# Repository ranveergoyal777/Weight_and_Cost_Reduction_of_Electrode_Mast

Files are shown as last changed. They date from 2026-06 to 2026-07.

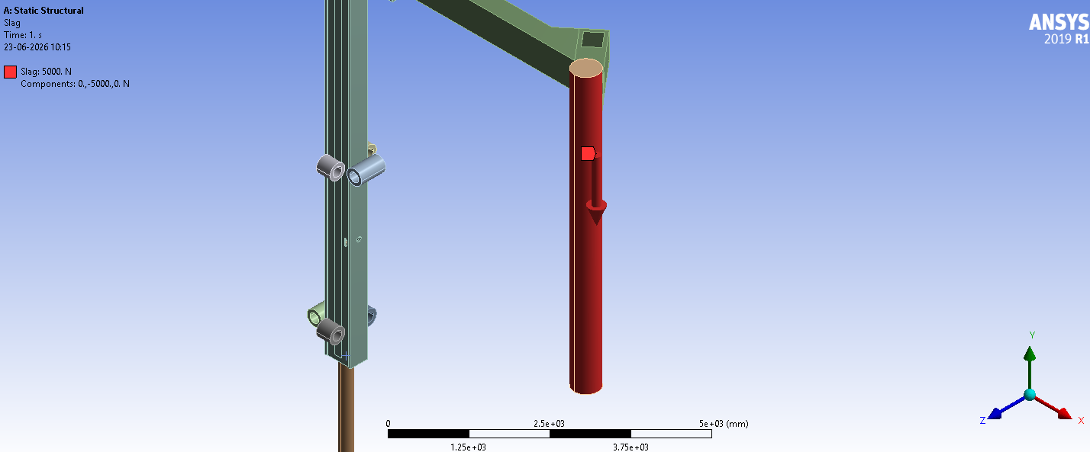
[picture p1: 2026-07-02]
508_Electrode/Side Mast 2/Photos 508 Side Mast 2/Screenshot 2026-06-23 101618.png

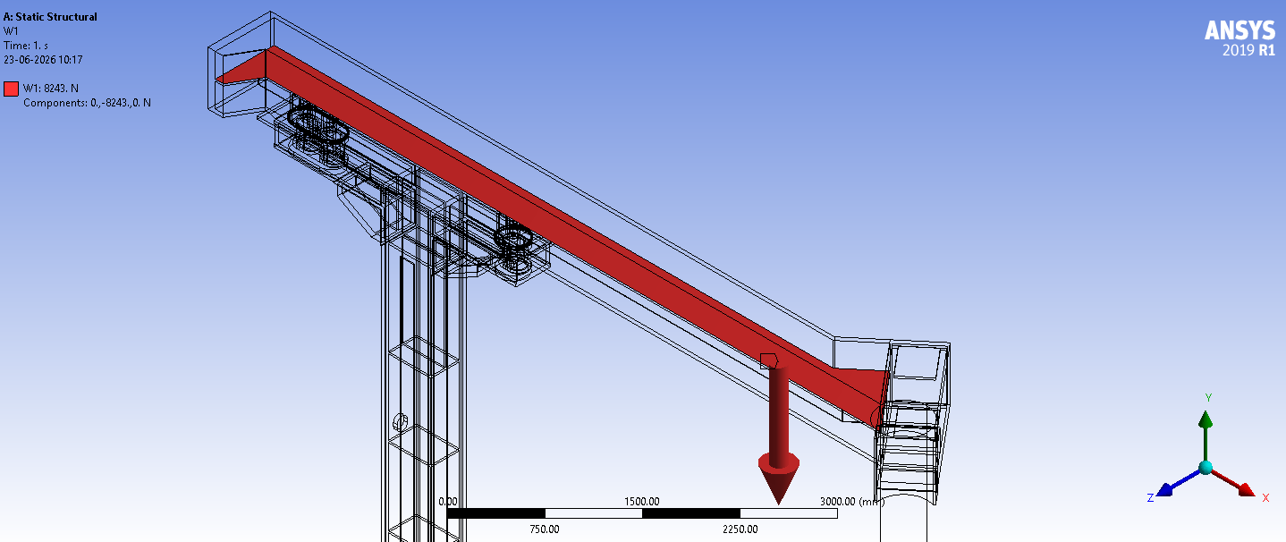
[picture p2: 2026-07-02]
508_Electrode/Side Mast 2/Photos 508 Side Mast 2/Screenshot 2026-06-23 103617.png

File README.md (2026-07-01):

# Weight & Cost Reduction of Electrode Mast – Ladle Heating Furnace (LHF)

Static structural FEA-based redesign of the electrode mast-arm assembly of a Ladle Heating Furnace, performed during a summer internship at **SMS India Pvt. Ltd.** (Metallurgy Department).

**Author:** Ranveer Goyal, B.Tech. Mechanical Engineering, IIT Ropar
**Duration:** 25 May 2026 – 3 July 2026 (6 weeks)
**Software:** SolidWorks · ANSYS Mechanical 2019 (Student)

## Overview

A Ladle Heating Furnace (LHF) uses graphite electrodes mounted on cantilevered mast-arm assemblies to arc-heat liquid steel during secondary refining. This project performs static structural FEA on the existing electrode mast-arm assemblies and proposes redesigned mast cross-sections that reduce weight and material cost while keeping stresses and deformations within allowable limits.

The work covers four configurations — side arm (E-ARM#1) and middle arm (E-ARM#2), for both 508 mm and 457 mm electrode variants — plus a comparative study of a cylindrical mast alternative.

## Methodology

1. **Manual calculations** – Free-body moment equilibrium to estimate support roller reactions and hydraulic cylinder base load, used to cross-check FEA results.
2. **CAD simplification (SolidWorks)** – Original assemblies simplified by removing non-structural hardware (pipes, brackets, fittings) while preserving internal water-cooling chambers. Removed mass compensated using an effective-density approach with a 1.3 factor of safety.
3. **FEA (ANSYS Mechanical 2019)** – Static structural analysis with frictional contact at the moment-resisting roller pair, bonded contacts elsewhere (validated against a full bolt-pretension study), and loads including self-weight, cooling water weight, dynamic water pressure (9 bar), dust load, cable weight, clamping unit weight, and slag force.
4. **Redesign & comparison** – Mast cross-sections reduced and re-analyzed; results compared against the original (Mast 1) design for stress, deformation, and base load.

## Key Results

| Configuration | Mast 1 → Mast 2 (cross-section) | Weight Reduction | Estimated Cost Saving |
|---|---|---|---|
| E-ARM#1, 508 mm | 600×410 → 550×350 mm | 14.9% (≈790 kg) | ≈ ₹3.16 lakhs |
| E-ARM#2, 508 mm | 600×410 → 550×350 mm | 15.4% (≈959 kg) | ≈ ₹3.84 lakhs |
| E-ARM#1, 457 mm | 550×400 → 500×310 mm (proposed) | 22.6% (≈1054 kg) | ≈ ₹4.21 lakhs |
| E-ARM#2, 457 mm | 550×400 → 500×310 mm | 20.4% (≈1270 kg) | ≈ ₹5.08 lakhs |

Across all configurations, peak stress and hydraulic cylinder base load were reduced or held essentially constant, while mast weight dropped by roughly 15–23%. The trade-off is increased total deformation, which remains within allowable limits in every case. A cylindrical mast alternative was also evaluated and found structurally inferior (higher stress and deformation) to the rectangular section, and was not pursued further.

## Repository Structure

```
.
├── 508_Electrode/
│   ├── Middle_Mast_1/
│   │   ├── *.stp                  # SolidWorks STEP model
│   │   ├── *.wbpj / ANSYS files   # ANSYS Workbench project and subsequent files
│   │   └── Result_Photos/         # ANSYS result plots (stress, deformation, etc.)
│   ├── Middle_Mast_2/
│   │   ├── *.stp
│   │   ├── ANSYS files
│   │   └── Result_Photos/
│   ├── Side_Mast_1/
│   │   ├── *.stp
│   │   ├── ANSYS files
│   │   └── Result_Photos/
│   └── Side_Mast_2/
│       ├── *.stp
│       ├── ANSYS files
│       └── Result_Photos/
│
├── 457_Electrode/
│   ├── Middle_Mast_1/
│   │   ├── *.stp
│   │   ├── ANSYS files
│   │   └── Result_Photos/
│   ├── Middle_Mast_2/
│   │   ├── *.stp
│   │   ├── ANSYS files
│   │   └── Result_Photos/
│   └── Side_Mast_1/
│       ├── *.stp
│       ├── ANSYS files
│       └── Result_Photos/
│   (no Side_Mast_2 — see note below)
│
├── Cylindrical_Mast/
│   ├── *.stp
│   ├── ANSYS files
│   └── Result_Photos/
│
└── Internship_Report.docx
```

**Note:** The 457 mm electrode configuration has no `Side_Mast_2` folder — the redesigned side-arm mast for this variant was not separately modelled/analyzed in ANSYS; it is a proposed design based on the validated results of the 457 mm middle arm redesign (see Section 9.3.2 of the report).

Each `Mast 1` folder contains the original cross-section model and results; each `Mast 2` folder contains the redesigned (weight/cost-reduced) cross-section model and results. The `Cylindrical_Mast` folder contains the standalone comparative study of a circular hollow section mast (Section 9.5 of the report), evaluated under the 508 mm middle-arm Mast 1 loading conditions.

## Acknowledgements

This project was carried out under the guidance of the Metallurgy Department at SMS India Pvt. Ltd., a subsidiary of SMS group GmbH.

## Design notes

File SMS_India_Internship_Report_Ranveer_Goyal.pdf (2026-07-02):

Internship Report – SMS India Pvt. Ltd. | Weight & Cost Reduction of Electrode Mast | Ranveer Goyal, IIT Ropar
SMS India Pvt. Ltd. | Summer Internship 2026 Page 1

# SUMMER INTERNSHIP REPORT

## Weight and Cost Reduction of Electrode Mast of the Ladle Heating Furnace

Submitted by

### Ranveer Goyal

2024MEB1375
B.Tech., Mechanical Engineering Indian Institute of Technology Ropar

Organization
SMS India Pvt. Ltd.
Metallurgy Department

Duration: 25 May 2026 – 3 July 2026 (6 Weeks)

## Table of Contents

## 1. Internship Overview

Organization | SMS India Pvt. Ltd.
Department | Metallurgy Department
Duration | 25 May 2026 – 3 July 2026 (6 Weeks)
Project Title | Weight and Cost Reduction of Electrode Mast of the Ladle Heating Furnace
Student | Ranveer Goyal – IIT Ropar (B.Tech. Mechanical Engineering)
Software Used | SolidWorks, ANSYS Mechanical 2019 Student

## 2. Introduction

2.1 About SMS India Pvt. Ltd.

SMS India Pvt. Ltd. is the Indian subsidiary of SMS group GmbH, a world-leading supplier of plant and machinery for the steel and non-ferrous metals industry. The Metallurgy Department focuses on primary and secondary steelmaking equipment including ladle furnaces and vacuum degassers. SMS group has supplied over 150 single-station and 40 twin-station ladle furnaces globally, with Indian installations at Bokaro, JSPL Angul, Tata Steel, JSW, SAIL, and AM/NS among others.

### 2.2 Project Objective

The objective of this project was to perform static structural FEA of the existing electrode mast and arm assemblies of a Ladle Heating Furnace (LHF), and to redesign selected mast cross-sections to achieve weight and material cost reduction while maintaining structural integrity under all operating loads.

- Study the LHF equipment and the steelmaking process.
- Perform manual force and moment calculations for the electrode mast-arm assembly.
- Rebuild simplified 3D models in SolidWorks suitable for FEA.
- Conduct static structural analysis in ANSYS Mechanical 2019 Student for both Ø508 mm and Ø457 mm electrode variants (side arm E-ARM#1 and middle arm E-ARM#2).
- Propose and validate redesigned mast cross-sections with reduced weight and cost.

## 3. Steelmaking Process Overview

As background for the LHF equipment studied in this project, a brief overview of the steelmaking route is given below.

Iron ore is processed through a sinter plant and reduced in a Blast Furnace (or via DRI) to produce liquid hot metal. This is converted to steel in a primary furnace — a Basic Oxygen Furnace (BOF), Electric Arc Furnace (EAF), or Conpro Furnace — depending on the plant configuration. The liquid steel is then tapped into a ladle and moved to the Ladle Heating Furnace (LHF) for secondary refining, where arc heating from graphite electrodes maintains the precise temperature required for casting, while alloying, desulphurization, and inert-gas stirring adjust the final chemistry. For high-grade steels, the ladle may additionally pass through a degassing unit (RH or VD/VOD) to remove dissolved gases. Finally, the refined steel is sent to the Continuous Casting Machine (CCM) and solidified into billets, blooms, slabs, or rounds for downstream rolling.

The LHF — the focus of this project — therefore functions as a critical buffer and refining station between primary steelmaking and casting, and its electrode mast-arm assembly must reliably withstand continuous mechanical and thermal loads during operation.

## 4. Ladle Heating Furnace – Equipment Description

### 4.1 LHF Types

Single-station LHFs have one treatment position and are compact and energy-efficient (30–350 t). Twin-station LHFs have two treatment positions sharing a common power supply, offering greater operational flexibility and are preferred for superior-quality steel grades (120–350 t).

### 4.2 Key Components

- Water-Cooled Roof: Dome-shaped or skirt-type, made of water-cooled pipes. Fitted with pneumatically-operated flap gates for sampling and temperature measurement, an alloy chute, wire feeding funnel, and fume elbow connecting to the fume extraction system.
- Electrode Regulation System: The SMS X-Pact® SynReg system regulates electrode position via a primary impedance/current control loop and a secondary dynamic adjustment loop, minimizing electrode consumption and energy use.
- Electrode Arms and Mast: The structural assembly that holds and positions the graphite electrodes (detailed in Section 5).
- High Current System: Flexible water-cooled cables carry the arc current from the transformer to the electrode arms.
- Argon Top Lance / Bottom Purging: For emergency stirring and inert gas homogenization through porous plugs.
- Wire Feeding Station: Feeds alloy or treatment wires into the ladle.
- Automatic Temperature & Sampling Lance: For automated steel temperature measurement and sampling.
- Fume Extraction System: Captures and cleans furnace off-gases.

## 5. Electrode Mast-Arm System Description

### 5.1 System Overview

The electrode mast-arm assembly is the structural backbone of the LHF. It supports and positions the three graphite electrodes (one per phase of the three-phase arc system) over the ladle. The system consists of one mast per electrode phase with a cantilevered arm. The mast translates vertically via a hydraulic cylinder to raise and lower the electrode.

### 5.2 Major Components

- Electrode Mast: The primary vertical structural member. It is a water-cooled hollow rectangular box section, with mast height varying from 6.8 m to 9.5 m depending on the configuration. Including the hydraulic cylinder stroke, the total assembly height can reach up to ~15 m. Internal water chambers (left, middle, and right) cool the mast during operation.
- Electrode Arm (E-ARM#1 – Side Arm, E-ARM#2 – Middle Arm): Cantilevered arms extending horizontally from the mast, carrying the graphite electrode at their tip. The arms contain upper and lower water-cooling chambers. The middle arm (E-ARM#2) is centrally located; the side arms (E-ARM#1) are positioned on either side.
- Graphite Electrode: Conducts the arc current to the steel bath. Standard diameters analyzed are 508 mm and 457 mm. Subject to arc force (slag force) at the tip.
- Insulating Plate: Electrically isolates the electrode arm from the mast to prevent current leakage to the structure. Connected via bolted joints.
- Support Rollers – Moment-Resisting Pair: The mast is guided along a vertical rail by a total of 8 rollers (front and back, left and right, upper and lower). One pair of diametrically-opposed rollers bears against the guide rail and reacts the overturning bending moment generated by the cantilevered arm weight. The vertical spacing between this roller pair is 3100 mm for the Ø508 mm electrode configuration (both arms) and 2900 mm for the Ø457 mm electrode configuration (both arms). The upper roller pushes in one direction; the lower roller reacts in the opposite direction, forming a moment couple.
- Support Rollers – Thermal Gap Pair: The rollers on the opposite side of the moment-resisting pair maintain a small clearance gap between them and the mast rail. This gap accommodates thermal expansion of the mast during furnace operation and prevents them from generating unwanted constraint loads under normal conditions.
- Hydraulic Cylinder: Raises and lowers the entire mast-arm assembly for electrode positioning. The cylinder rod (bottom) is fixed to the gantry structure.
- Clamping Unit: Clamps the graphite electrode securely at the arm tip. Its weight (732 kg) acts at the top surface of the arm tip.
- Water Cooling Cables (W.C. Cables): Flexible water-cooled cables carrying high current. Their weight, taken as 1565 kg, acts at the rear side of the arm.
- Cooling Water Hoses: Supply and return hoses for mast cooling water.

### 5.3 Electrode Variants Analyzed

Electrode Dia. | Arm Type | Mast 1 (Original) X-section | Mast 2 (Redesigned) X-section
508 mm | E-ARM#2 (Middle Arm) | 600 × 410 mm | 550 × 350 mm + stiffener plate
508 mm | E-ARM#1 (Side Arm) | 600 × 410 mm | 550 × 350 mm + stiffener plate
457 mm | E-ARM#1 (Side Arm) | 550 × 400 mm | Not redesigned (Mast 1 only)
457 mm | E-ARM#2 (Middle Arm) | 550 × 400 mm | 500 × 310 mm

For the Ø457 mm electrode configuration, the redesigned Mast 2 (500 × 310 mm) also incorporated plate thickness changes: the original 40 mm major-axis plate was increased to 42 mm, while the 25 mm minor-axis plate was reduced to 20 mm. For the Ø508 mm electrode configuration, the major-axis plate thickness (42 mm) was kept unchanged, while the minor-axis plate thickness was reduced from 25 mm to 20 mm.

### 5.4 Materials Used

Mast and Arm Structure (Structural Steel S355):

Property | Value | Unit
Material Grade | S355 | –
Yield Strength fy | 355 | MPa
Ultimate Strength fu | 510 | MPa
Elastic Modulus E | 210,000 | MPa
Shear Modulus G | 81,000 | MPa
Density ρ | 7,850 | kg/m³
Poisson's Ratio ν | 0.3 | –
Thermal Expansion α | 1.2 × 10⁻⁵ | /°C
Temperature Rise (operating) | 110 | °C
Thermal Stress σthermal | 6.3 | MPa

Insulating Plate (EP GC 203 – epoxy glass-cloth laminate):

Property | Value | Unit
Material Grade | EP GC 203 | –
Density ρ | 2,470 | kg/m³
Young's Modulus E | 22 | GPa
Poisson's Ratio ν | 0.2 | –

Electrode (Graphite):

Property | Value | Unit
Material | Graphite | –
Density ρ | 1,800 | kg/m³
Young's Modulus E | 10 | GPa
Poisson's Ratio ν | 0.2 | –

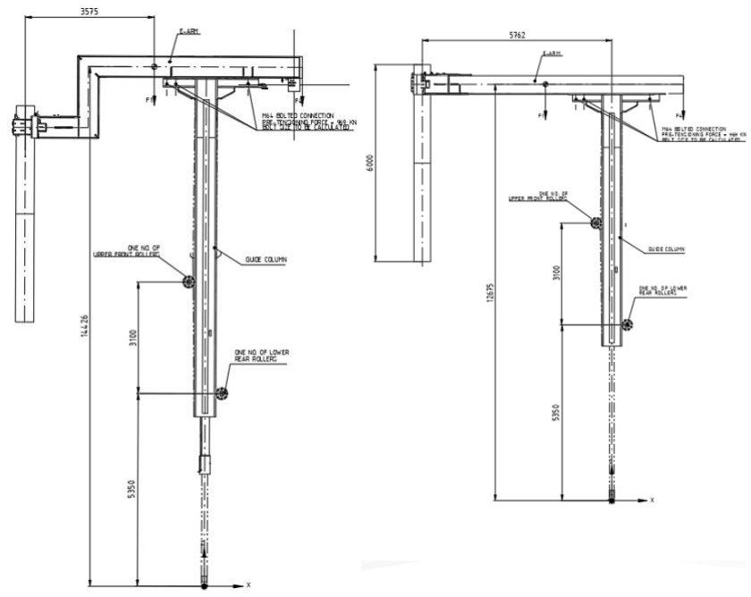
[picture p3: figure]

1. Middle and side sketches

## 6. Manual Force and Moment Calculations

Before proceeding with FEA, manual calculations were performed to estimate the reaction forces at the support rollers and the load on the hydraulic cylinder base. These results were used to verify the FEA model.

### 6.1 Methodology

The entire electrode mast-arm assembly was treated as a free body. The total bending moment about the support roller pair was found using the centre of gravity (CG) and weight of each component. Roller reactions were then calculated using moment equilibrium:

Ra = M / A | and | Rb = −Ra

where A = roller vertical spacing (3100 mm for the Ø508 mm electrode, both arms; 2900 mm for the Ø457 mm electrode, both arms)

The total vertical (axial) load on the hydraulic cylinder base equals the sum of all component weights, including the FOS-adjusted effective densities described in Section 7.3.

Cross-product mechanics were used to resolve the moments generated by each load (self-weight, water, dust, cables, clamping unit, slag) about the roller axis, producing the bending moment and roller reaction forces used to cross-check the corresponding ANSYS results in Section 9.

## 7. 3D Model Preparation in SolidWorks

### 7.1 Original Models

The original CAD assemblies of the electrode mast-arm system were provided in SolidWorks/STEP format. Each assembly included the mast, arm, electrode, insulating plate, support rollers, hydraulic cylinder, and numerous auxiliary components: pipes, hose connectors, clamps, cable brackets, and instrumentation fittings.

### 7.2 Model Simplification Strategy

Small auxiliary components significantly increase mesh element count and computation time without meaningfully affecting the global stress or deformation results. The following simplification approach was adopted:

- Removed: Pipes, hose fittings, small clamps, cable brackets, and miscellaneous hardware.
- Retained: Mast body (with internal water chambers), electrode arm, graphite electrode, insulating plate, support rollers, and hydraulic cylinder.
- Hollow internal volumes of water chambers in the mast (left/middle/right) and arm (upper/lower) were preserved intact for accurate water volume and pressure loading.
- Bodies were merged where necessary and internal geometry verified using SolidWorks Section View and Mass Properties.

### 7.3 Effective Density Compensation

To account for the mass of removed components without re-adding geometric complexity, the effective density of the mast and arm bodies was adjusted:

ρ_eff | = | (Real Total Mass of Assembly) / (Simplified Model Volume)
An additional Factor of Safety (FOS) of 1.3 was then applied by multiplying the effective density by 1.3, to conservatively account for thermal stresses and operational dynamic loads (vibration, impact from sudden stopping):
ρ_applied | = | 1.3 × ρ_eff

This same FOS of 1.3 was also applied to the water weight loads and other external forces (cables, clamping unit) to produce conservative loading. The dust load and slag force were applied without this FOS multiplier.

### 7.4 STEP File Export

Simplified assemblies were exported as STEP (.stp) files for import into ANSYS Mechanical 2019. STEP format ensures geometry fidelity and is fully compatible with ANSYS DesignModeler.

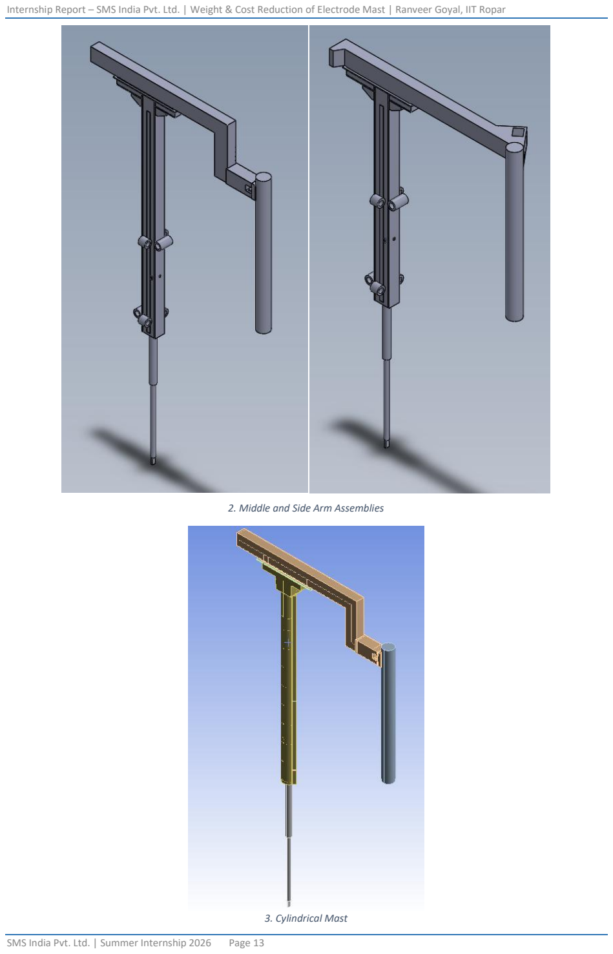
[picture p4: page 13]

2. Middle and Side Arm Assemblies
3. Cylindrical Mast

## 8. Finite Element Analysis – ANSYS Mechanical 2019

### 8.1 Material Properties

Material properties were entered in ANSYS Engineering Data for each part: structural steel (S355) for the mast, arm, and hydraulic cylinder with adjusted effective density (see Section 7.3); EP GC 203 epoxy glass-cloth laminate for the insulating plate; and graphite for the electrode (properties listed in Section 5.4).

### 8.2 Contact Definitions

The following contact pairs were defined, based on the actual contact setup used for the side and middle arm models:

Contact Pair | Type | Remarks
Support Rollers – Mast (guide column) | Frictional (μ = 0.03) | Upper-front and lower-rear roller only; 6 mm strip for surface contact.
Mast (Guide Column) – Electrode Arm | Bonded | Full attachment
Mast – Insulation – Electrode Arm | Bonded | Three-body bonded joint
Mast – Hydraulic Cylinder | Bonded | Full attachment
Electrode – Electrode Arm | Bonded | Full attachment

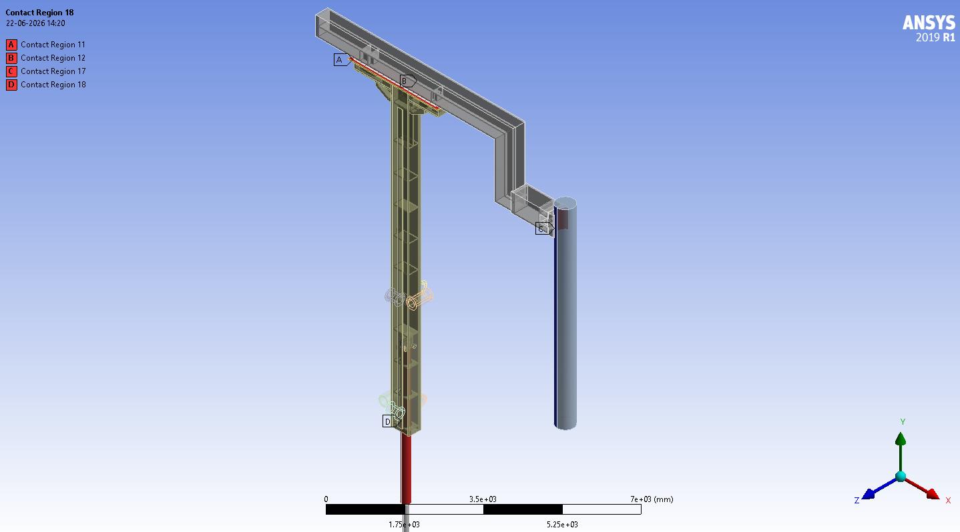
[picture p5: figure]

4. Bonded Contacts

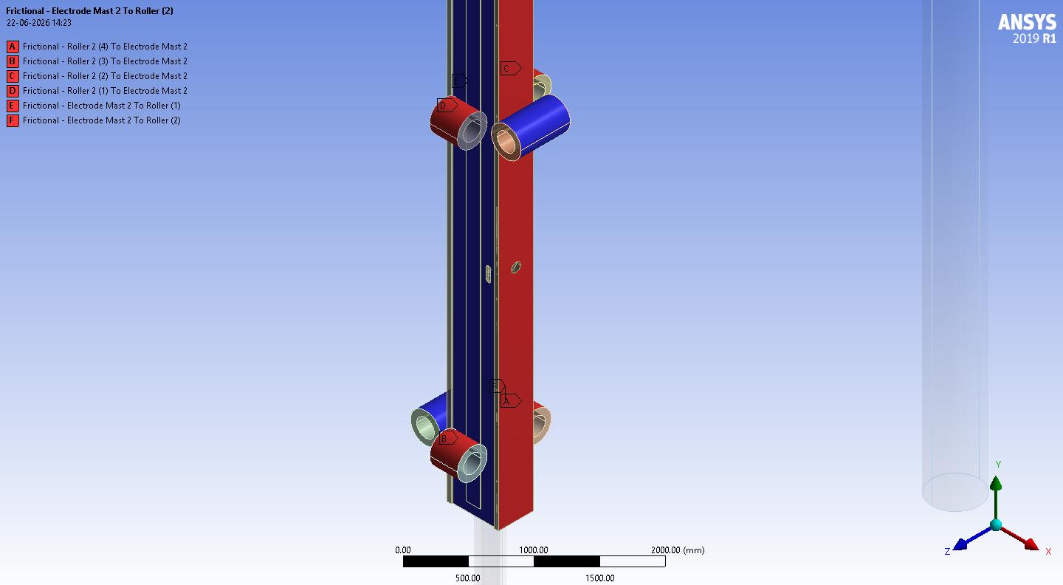
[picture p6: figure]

5. Frictional Contacts

### 8.3 Bolt Pretension Study

The insulating plate is connected to the mast and arm by bolted joints. Applying bolt pretension in ANSYS requires a multi-step solver with separate load steps, significantly increasing computation time. A comparative study was performed:

- Case A: Full bolt pretension on all bolts.
- Case B: Bolts replaced with bonded contacts (no pretension).

Findings:

- Total deformation difference: Less than 0.1 mm (negligible for this scale of assembly).
- Equivalent stress difference: Only local stress concentrations at bolt locations due to the pretension force; the global stress field was essentially identical.
Conclusion: Bonded contact is an adequate approximation for this global structural assessment. All subsequent analyses used bonded contacts, saving significant computation time.

### 8.4 Boundary Conditions

All support rollers (the moment-resisting line-contact pair as well as the remaining rollers) were given fixed support in every configuration analyzed. The hydraulic cylinder rod (bottom) was also fixed. The roller pair on the side opposite the moment-resisting pair maintains a clearance gap from the mast rail to accommodate thermal expansion (Section 5.2) and is therefore not engaged under normal operating loads.

6. Fixed Constraints on rollers

### 8.5 Mesh Settings

Global element size: 100 mm. Mesh sensitivity was assessed at 75 mm; peak deformation difference was only 0.1–0.2 mm, confirming that 100 mm is adequate for this large assembly (mast height 6.8–9.5 m, with the total assembly height — including hydraulic cylinder stroke — reaching up to ~15 m).

Component | Mesh Method | Reason
Electrode | Sweep | Cylindrical geometry
Support Rollers | Sweep | Cylindrical geometry
Mast, Arm, Insulating Plate, Hydraulic Cylinder | Tetrahedral Patch Conforming | Complex irregular geometry

### 8.6 Applied Loads

### 8.6.1 Standard Earth Gravity

Gravity of 9.81 m/s² applied in the −Y direction to account for self-weight of all components.

### 8.6.2 Cooling Water Weight

The weight of static cooling water in each chamber was calculated using the internal volume measured in SolidWorks:

F_water = V_chamber × ρ_water × g

Applied separately for: Mast left chamber, Mast middle chamber, Mast right chamber, Arm upper chamber, Arm lower chamber. Water weight forces were multiplied by FOS = 1.3.

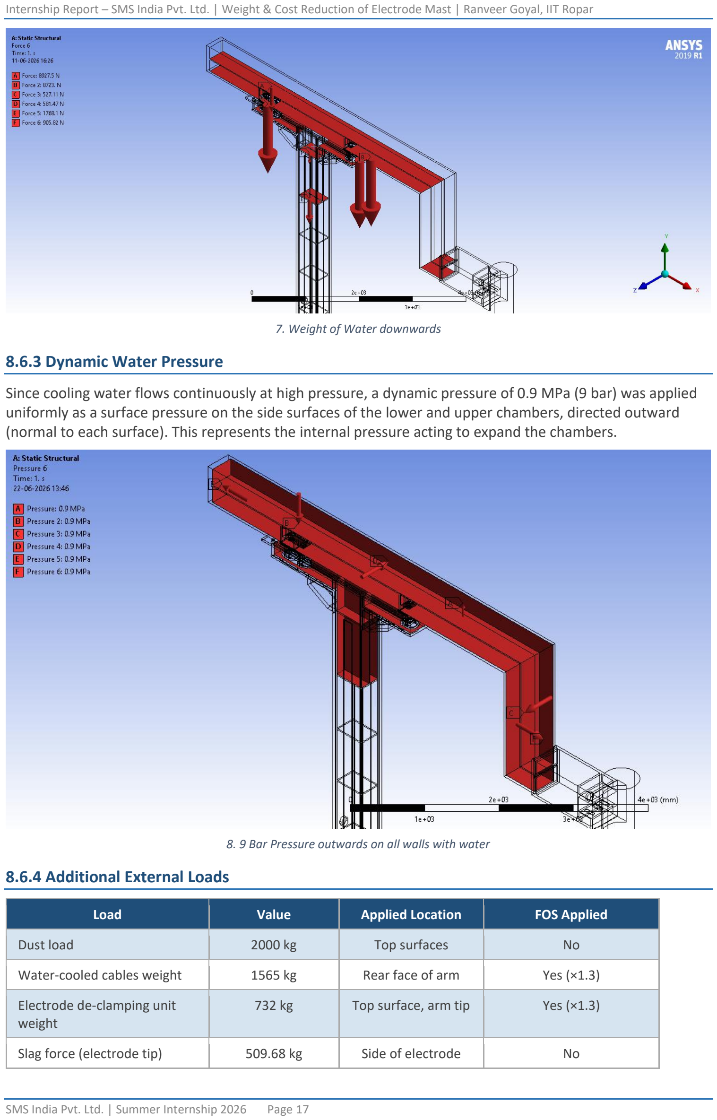
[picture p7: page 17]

7. Weight of Water downwards

### 8.6.3 Dynamic Water Pressure

Since cooling water flows continuously at high pressure, a dynamic pressure of 0.9 MPa (9 bar) was applied uniformly as a surface pressure on the side surfaces of the lower and upper chambers, directed outward (normal to each surface). This represents the internal pressure acting to expand the chambers.

8. 9 Bar Pressure outwards on all walls with water

### 8.6.4 Additional External Loads

Load | Value | Applied Location | FOS Applied
Dust load | 2000 kg | Top surfaces | No
Water-cooled cables weight | 1565 kg | Rear face of arm | Yes (×1.3)
Electrode de-clamping unit weight | 732 kg | Top surface, arm tip | Yes (×1.3)
Slag force (electrode tip) | 509.68 kg | Side of electrode | No

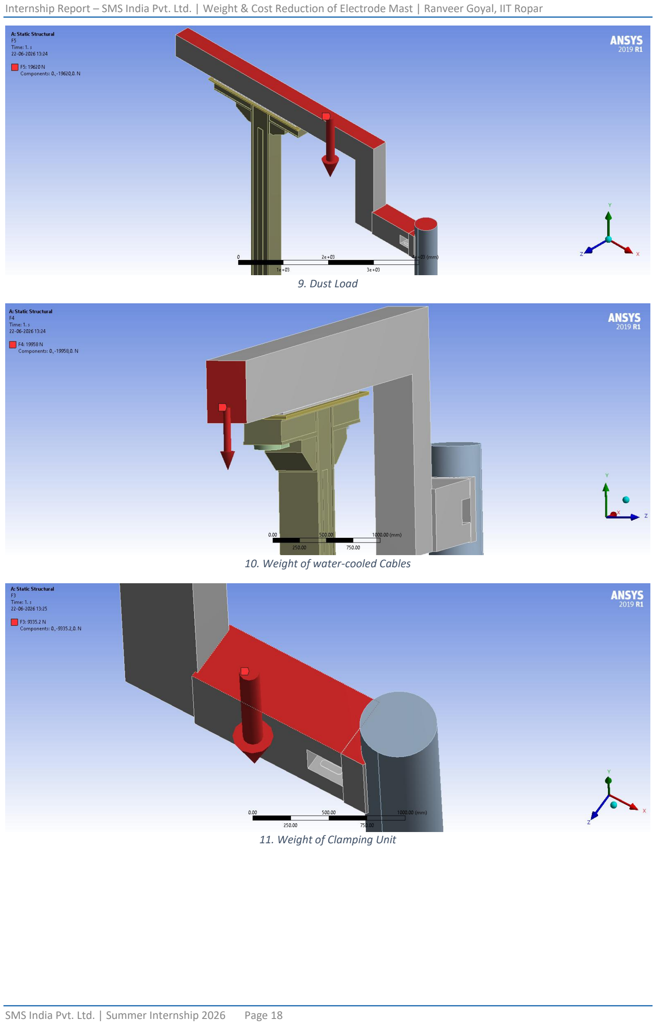
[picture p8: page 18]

9. Dust Load
10. Weight of water-cooled Cables
11. Weight of Clamping Unit

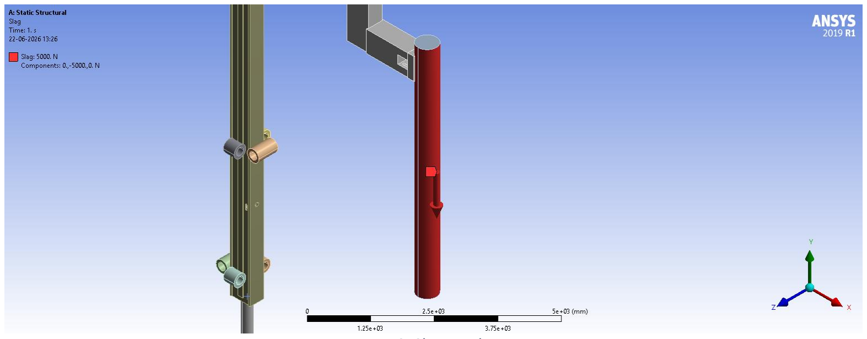
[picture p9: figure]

12. Slag Load

## 9. FEA Results

For each configuration, the following results were extracted: Equivalent (Von Mises) Stress, Total Deformation, Directional Deformation (X, Y, and Z where recorded), and Reaction Forces at the support rollers and hydraulic cylinder base. Directional deformation values are reported as magnitudes — the sign in the raw ANSYS output only indicates direction along the respective axis. All forces below include FOS = 1.3 already applied where applicable. Image placeholders are left below each result for the corresponding ANSYS plots. All values obtained are within the allowable deformation limits for the assembly.

### 9.1 E-ARM#1 (Side Arm) – Ø508 mm Electrode

Electrode length: 6000 mm. Note: weight of the online electrode jointer is not considered. Roller vertical spacing: 3100 mm.

### 9.1.1 Mast 1 (Original: 600 mm × 410 mm)

Loads: Upper chamber water 8243 N, Lower chamber water 7826.9 N, Mast water (W3, W4, W5) 698.62 N / 614.07 N / 3521 N, Dust load (no FOS), Water-cooled cables + water 19958 N, Slag on electrode (no FOS), Electrode de-clamping unit weight 9335.2 N, Pressure 0.9 MPa (9 bar) applied on the side surfaces of the lower and upper chambers.

Equivalent (Von Mises) Stress – Max (in mast) | 131.5 MPa
Total Deformation – Max (at electrode tip) | 34.247 mm
Deformation – Electrode Arm (range) | 12 – 25 mm (max 27 mm at clamping area)
Deformation – Mast | 8.5 mm
Directional Deformation X – Max | 19.823 mm
Directional Deformation Y – Max | 27.731 mm
Directional Deformation Z – Max | 4.755 mm
Reaction Force – Upper Roller (−ve x-direction) | 127,900 N
Reaction Force – Lower Roller (+ve x-direction) | 127,750 N
Reaction Force – Cylinder Rod | 192.48 kN

13. Equivalent Stress
14. Total Deformation
15. Deformation probes

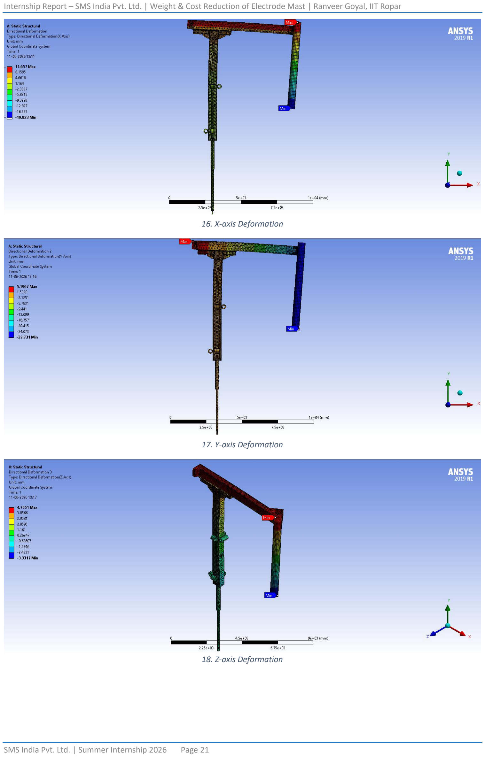
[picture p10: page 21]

16. X-axis Deformation
17. Y-axis Deformation
18. Z-axis Deformation

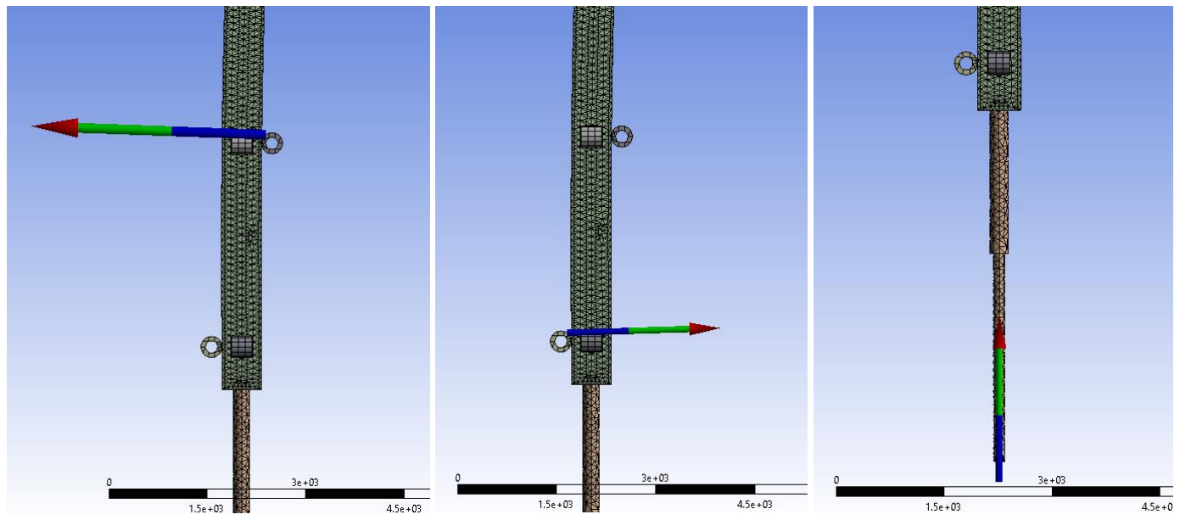
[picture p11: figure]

19. Reaction Forces on the Rollers and Hydraulic Cylinder

### 9.1.2 Mast 2 (Redesigned: 550 mm × 350 mm, plate added at mast top)

Cross-section altered from 600 × 410 mm to 550 × 350 mm; a plate was added to the top of the mast to counter stress. All constraints, boundary conditions, and electrode-arm load conditions are unchanged from Mast 1. Mast water loads updated: W3 (699.62 N → 581.47 N), W4 (614.07 N → 527.11 N), W5 (3521 N → 1768.1 N); the added top plate exerts an additional 905.82 N due to the water column.

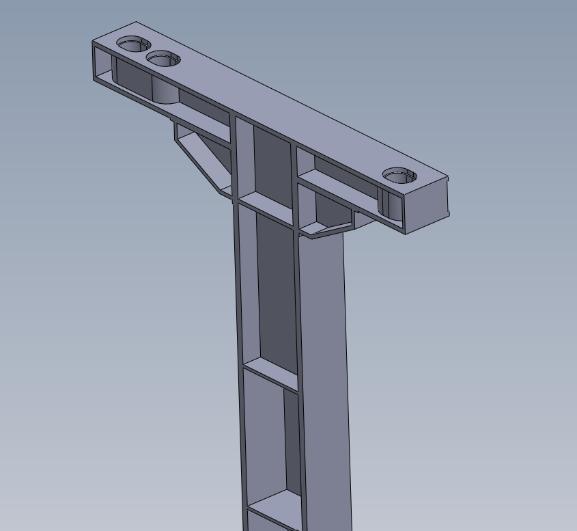
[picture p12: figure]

20. Added an extra plate in the mast
Equivalent (Von Mises) Stress – Max (in mast) | 102.88 MPa
Total Deformation – Max (at electrode tip) | 41.56 mm
Deformation – Electrode Arm (range) | 15 – 30 mm (max 35 mm at gripping point)
Directional Deformation X – Max | 22.64 mm
Directional Deformation Y – Max | 34.66 mm
Reaction Force – Lower Roller (+ve x-direction) | 127.8 kN
Reaction Force – Upper Roller (−ve x-direction) | 128 kN
Reaction Force – Cylinder Rod | 178.84 kN

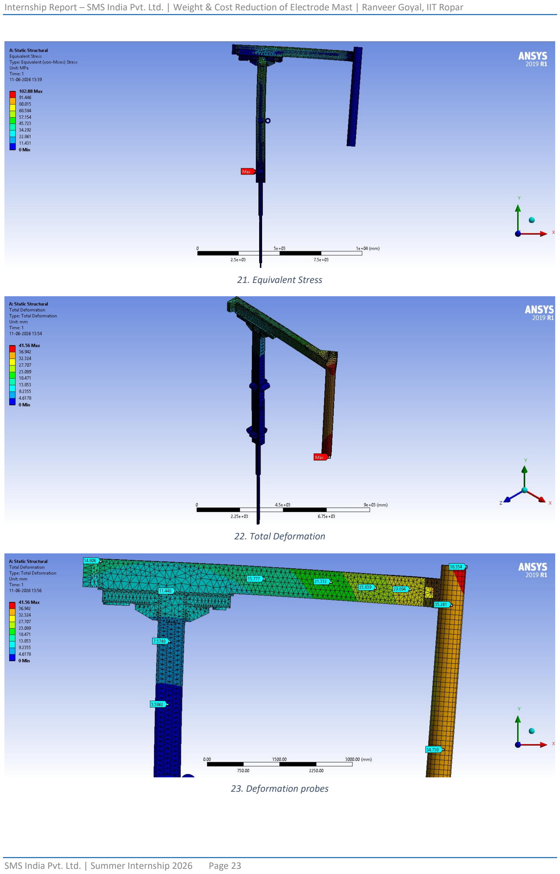
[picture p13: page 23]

21. Equivalent Stress
22. Total Deformation
23. Deformation probes

24. X-axis Deformation
25. Y-axis Deformation
26. Z-axis Deformation

### 9.2 E-ARM#2 (Middle Arm) – Ø508 mm Electrode

Note: weight of the online electrode jointer is not considered. Roller vertical spacing: 3100 mm.

### 9.2.1 Mast 1 (Original: 600 mm × 410 mm)

Loads: Upper chamber water 8927.5 N, Lower chamber water 8723 N, Mast water (W3, W4, W5) 614.07 N / 698.62 N / 3521 N, Dust load (no FOS), Water-cooled cables + water 19958 N, Slag on electrode arm (no FOS), Electrode de-clamping unit weight 9335.2 N, Pressure 0.9 MPa (9 bar) applied on the side surfaces of the lower and upper chambers.

Equivalent (Von Mises) Stress – Max | 91.017 MPa
Total Deformation – Max (at electrode tip) | 32.878 mm
Deformation – Electrode Arm (range) | 12 – 18 mm (max 20.5 mm at gripping point)
Directional Deformation X – Max | 23.897 mm
Directional Deformation Y – Max | 22.587 mm
Reaction Force – Upper Roller (−ve x-direction) | 95,966 N
Reaction Force – Lower Roller (+ve x-direction) | 95,821 N

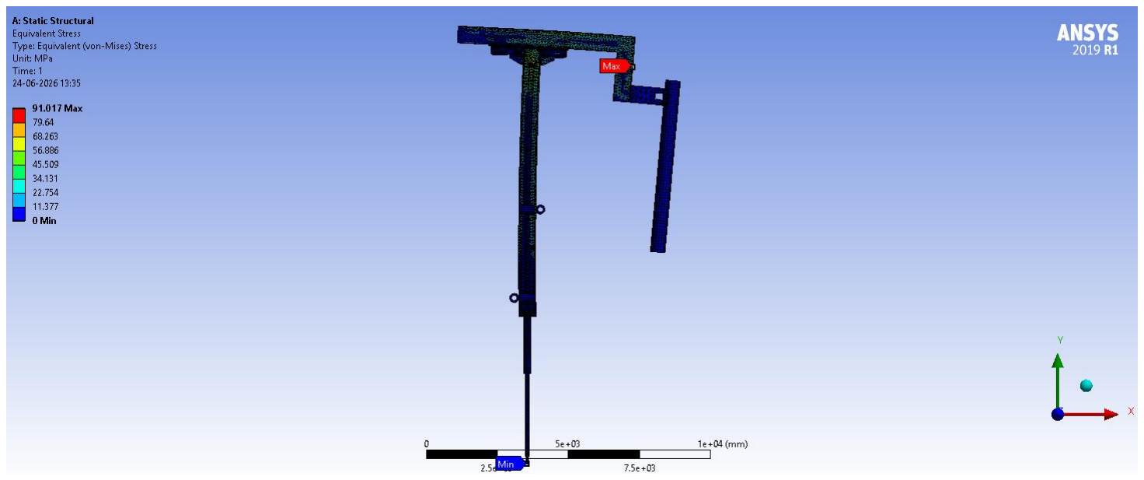
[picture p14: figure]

27. Equivalent Stress

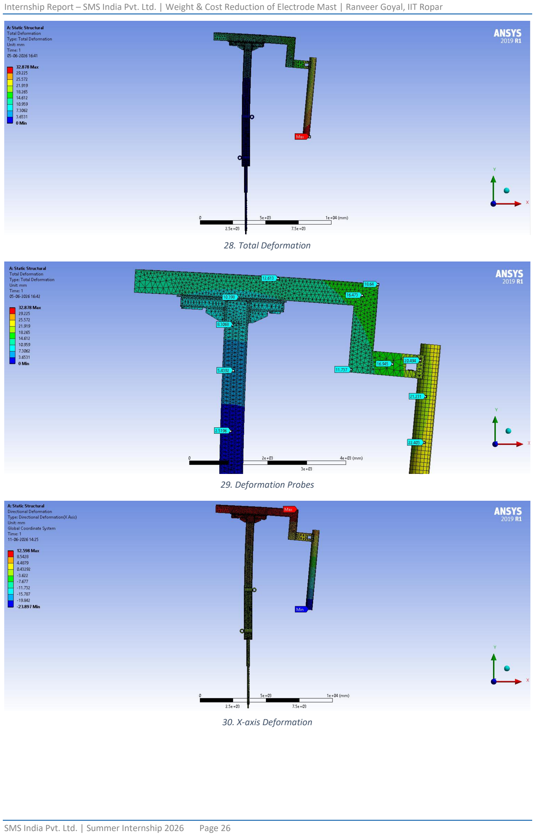
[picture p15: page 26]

28. Total Deformation
29. Deformation Probes
30. X-axis Deformation

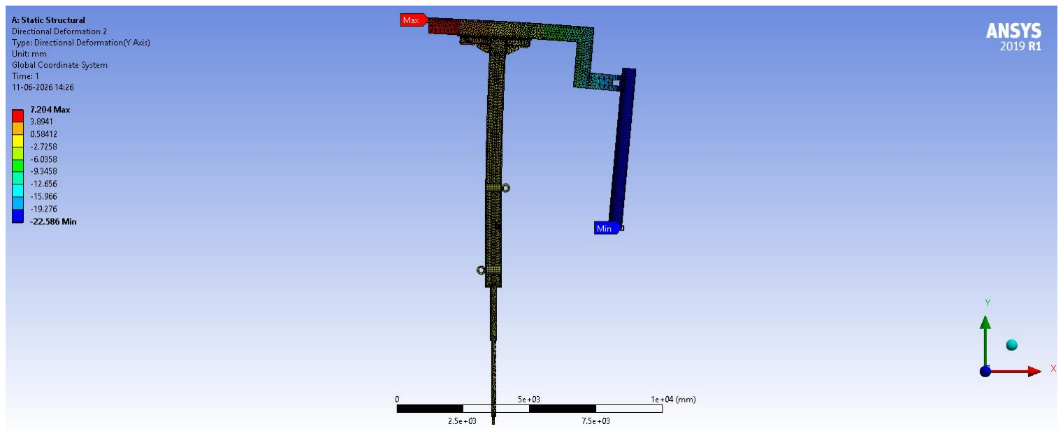
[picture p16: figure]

31. Y-axis Deformation

### 9.2.2 Mast 2 (Redesigned: 550 mm × 350 mm, plate added at mast top)

Cross-section altered from 600 × 410 mm to 550 × 350 mm; a plate was added to the top of the mast to counter stress. All electrode-arm load conditions unchanged. Mast water loads updated: W3 (614.07 N → 527.11 N), W4 (698.62 N → 581.47 N), W5 (3521 N → 1768.1 N); the added top plate exerts an additional 905.82 N due to the water column.

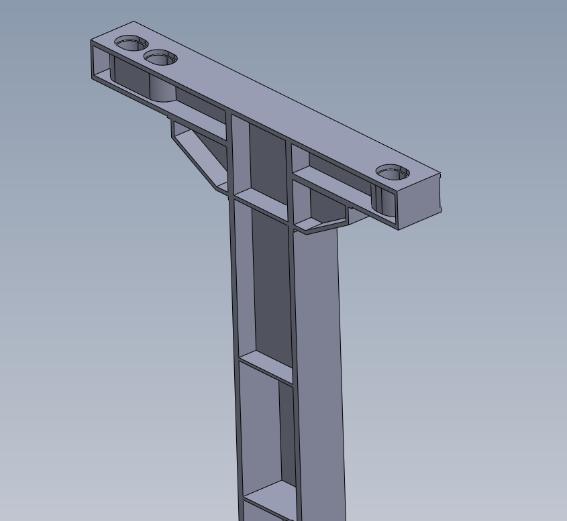
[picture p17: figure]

32. Added an extra plate in the mast
Equivalent (Von Mises) Stress – Max | 91.02 MPa
Total Deformation – Max (at electrode tip) | 39.875 mm
Deformation – Electrode Arm (range) | 18 – 24 mm (max 30 mm at gripping point)
Directional Deformation X – Max | 27.71 mm
Directional Deformation Y – Max | 28.674 mm
Reaction Force – Upper Roller (−ve x-direction) | 95,898 N
Reaction Force – Lower Roller (+ve x-direction) | 95,723 N

33. Equivalent Stress
34. Total Deformation
35. Deformation Probes

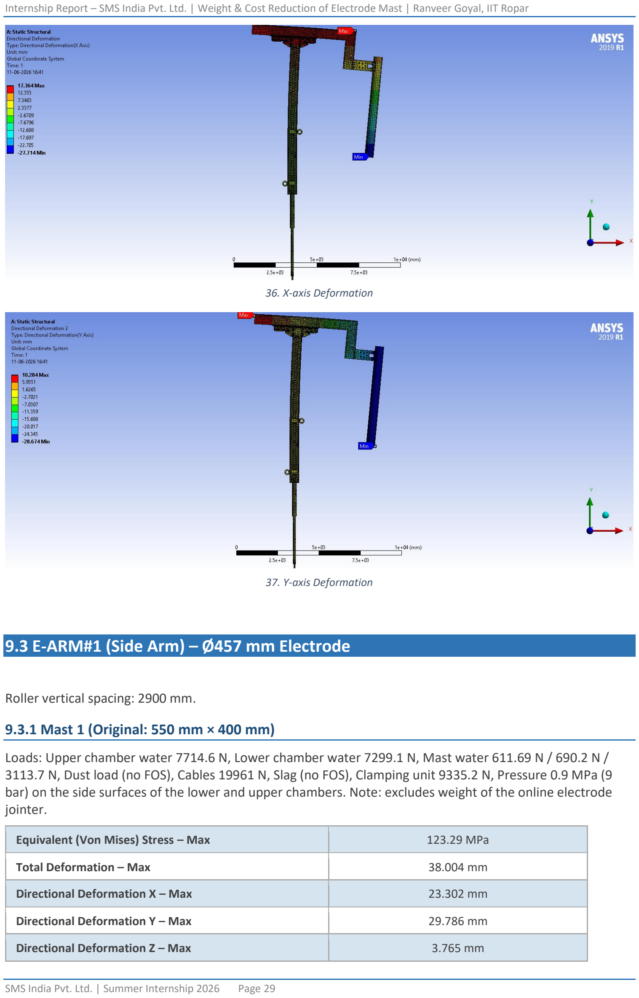
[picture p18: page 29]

36. X-axis Deformation
37. Y-axis Deformation

### 9.3 E-ARM#1 (Side Arm) – Ø457 mm Electrode

Roller vertical spacing: 2900 mm.

### 9.3.1 Mast 1 (Original: 550 mm × 400 mm)

Loads: Upper chamber water 7714.6 N, Lower chamber water 7299.1 N, Mast water 611.69 N / 690.2 N / 3113.7 N, Dust load (no FOS), Cables 19961 N, Slag (no FOS), Clamping unit 9335.2 N, Pressure 0.9 MPa (9 bar) on the side surfaces of the lower and upper chambers. Note: excludes weight of the online electrode jointer.

Equivalent (Von Mises) Stress – Max | 123.29 MPa
Total Deformation – Max | 38.004 mm
Directional Deformation X – Max | 23.302 mm
Directional Deformation Y – Max | 29.786 mm
Directional Deformation Z – Max | 3.765 mm

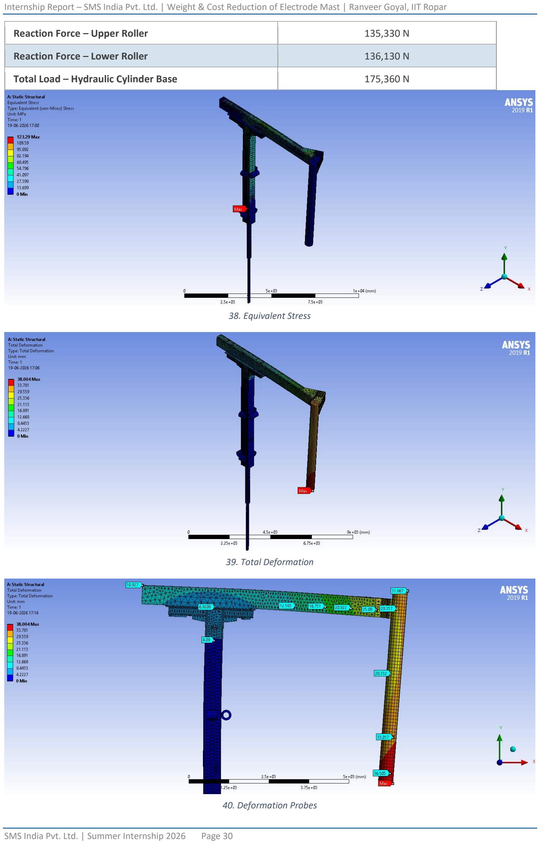
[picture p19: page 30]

Reaction Force – Upper Roller | 135,330 N
Reaction Force – Lower Roller | 136,130 N
Total Load – Hydraulic Cylinder Base | 175,360 N
38. Equivalent Stress
39. Total Deformation
40. Deformation Probes

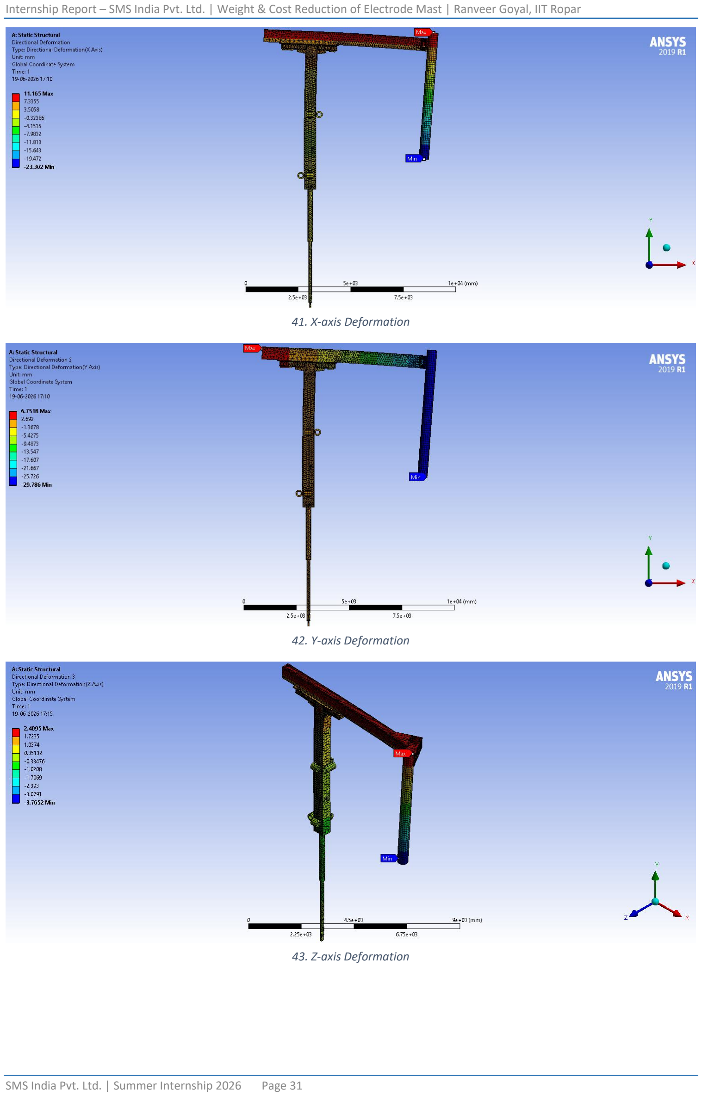
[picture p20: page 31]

41. X-axis Deformation
42. Y-axis Deformation
43. Z-axis Deformation

### 9.3.2 Mast 2 (Redesigned – proposed)

By the time the Ø457 mm side arm (E-ARM#1) was analyzed, optimized designs had already been validated for both the Ø508 mm side arm and the Ø457 mm middle arm (E-ARM#2). Based on this experience, it was concluded that the same redesign approach validated for the Ø457 mm middle arm — cross-section reduced from 550 × 400 mm to 500 × 310 mm, with the major-axis plate thickness increased from 40 mm to 42 mm and the minor-axis plate thickness reduced from 25 mm to 20 mm — could be directly applied to the Ø457 mm side arm to achieve similarly favourable results (reduced stress and base load with an acceptable increase in deformation), without requiring a fresh redesign-and-optimization cycle.

### 9.4 E-ARM#2 (Middle Arm) – Ø457 mm Electrode

Roller vertical spacing: 2900 mm.

### 9.4.1 Mast 1 (Original: 550 mm × 400 mm)

Loads: Upper chamber water 6873.3 N, Lower chamber water 6509.6 N, Mast water 611.69 N / 690.2 N / 3113.7 N, Dust load (no FOS), Cables 19961 N, Slag (no FOS), Clamping unit 9335.2 N, Pressure 0.9 MPa (9 bar) on the side surfaces of the lower and upper chambers.

Equivalent (Von Mises) Stress – Max | 92.214 MPa
Total Deformation – Max | 34.583 mm
Directional Deformation X – Max | 25.152 mm
Directional Deformation Y – Max | 23.736 mm
Reaction Force – Upper Roller | 102,020 N
Reaction Force – Lower Roller | 101,980 N
Total Load – Hydraulic Cylinder Base | 183,380 N
44. Equivalent Stress

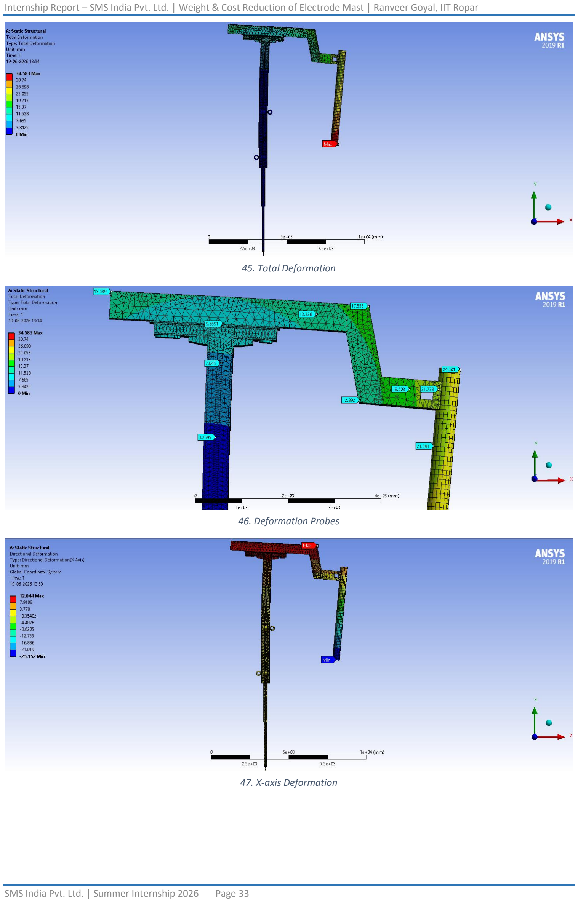
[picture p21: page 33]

45. Total Deformation
46. Deformation Probes
47. X-axis Deformation

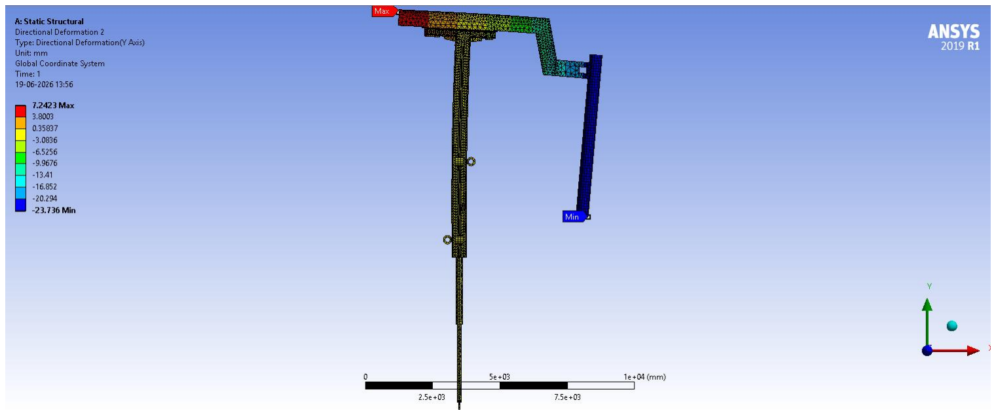
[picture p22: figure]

48. Y-axis Deformation

### 9.4.2 Mast 2 (Redesigned: 500 mm × 310 mm)

Cross-section reduced from 550 × 400 mm to 500 × 310 mm. The 40 mm major-axis plate thickness was increased to 42 mm; the 25 mm minor-axis plate thickness was reduced to 20 mm. Mast water weight recalculated for the new internal volumes: 6873.3 N, 6509.6 N, 487.68 N, 455.03 N, 1583.3 N, 476.94 N. All other forces (dust, cables, slag, clamping unit, pressure) unchanged from Mast 1.

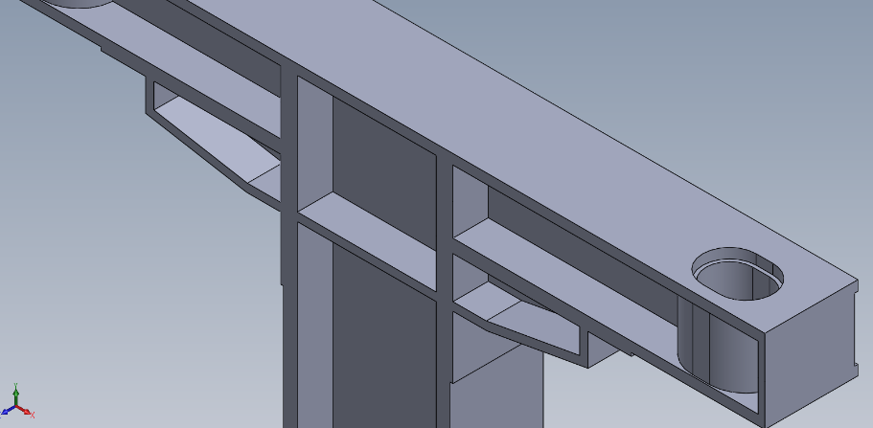
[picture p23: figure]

49. Added an extra plate in the mast
Equivalent (Von Mises) Stress – Max | 83.724 MPa
Total Deformation – Max | 46.614 mm
Directional Deformation X – Max | 32.128 mm
Directional Deformation Y – Max | 33.775 mm
Reaction Force – Upper Roller | 103,690 N
Reaction Force – Lower Roller | 104,700 N
Total Load – Hydraulic Cylinder Base | 165,870 N (~9.5% reduction)

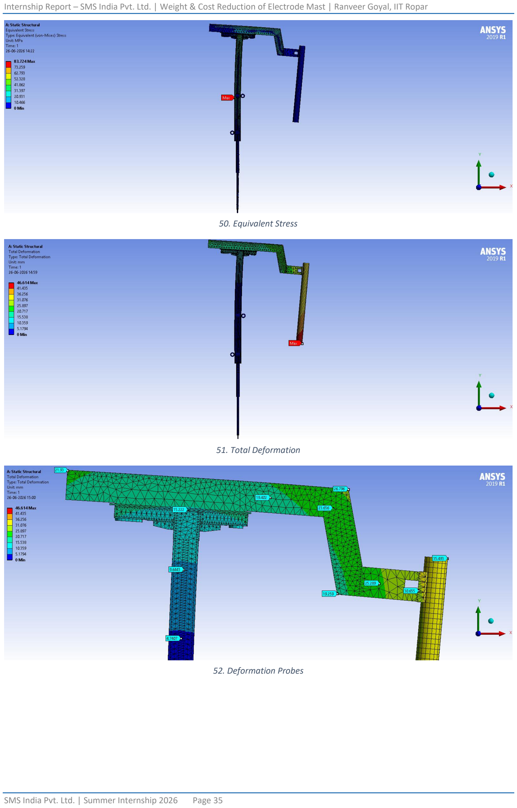
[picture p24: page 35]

50. Equivalent Stress
51. Total Deformation
52. Deformation Probes

53. X-axis Deformation
54. Y-axis Deformation

### 9.5 Cylindrical Mast Study

A circular hollow section (cylindrical) mast was modeled and analyzed as an alternative to the standard rectangular hollow section, using the same loading conditions, pressures, and fixed supports as the E-ARM#2 (Middle Arm), Ø508 mm electrode, Mast 1 configuration (Section 9.2.1). The mast water weights used were 8927.5 N, 8723 N, 583.63 N, 669.19 N, 4051.5 N, and 584.64 N.

Equivalent (Von Mises) Stress – Max | 95.471 MPa
Total Deformation – Max | 39.791 mm
Directional Deformation X – Max | 27.534 mm
Directional Deformation Y – Max | 28.693 mm

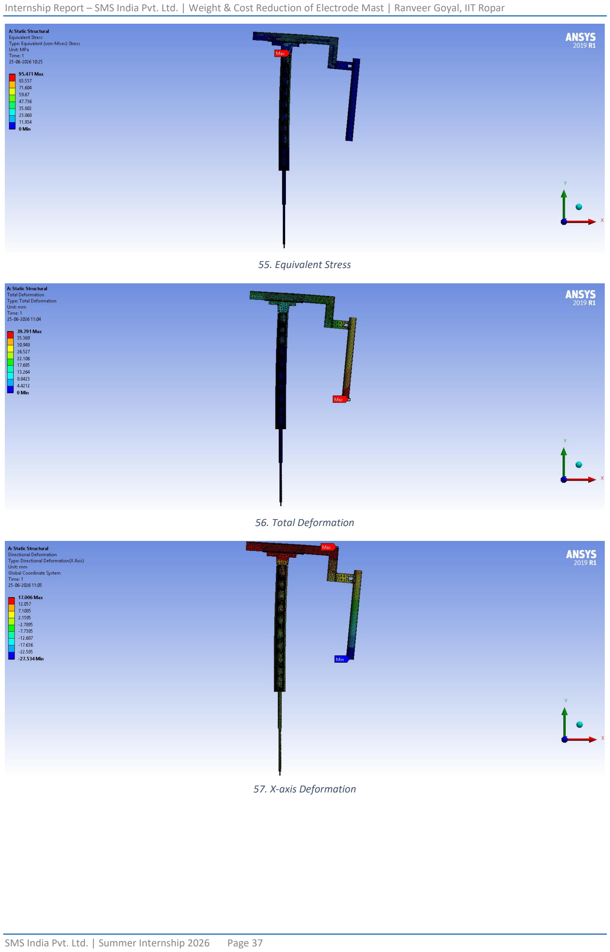
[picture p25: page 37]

55. Equivalent Stress
56. Total Deformation
57. X-axis Deformation

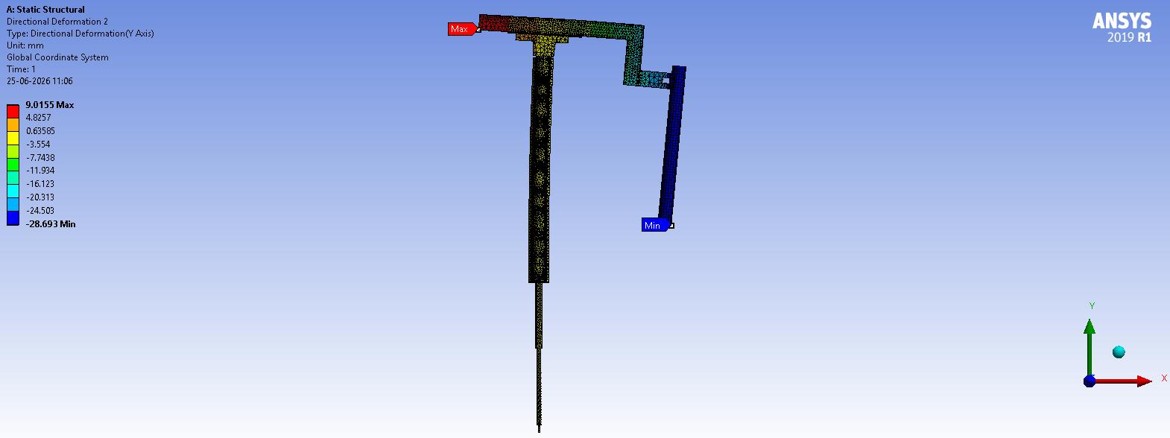
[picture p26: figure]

58. Y-axis Deformation
- Compared to the rectangular Mast 1 for the same configuration (91.017 MPa, 32.878 mm), the cylindrical mast shows both higher peak stress (95.471 MPa) and higher total deformation (39.791 mm).
- This confirms a lower effective bending stiffness for the cylindrical cross-section compared to the equivalent rectangular section, for the same loading conditions.
- Conclusion: The cylindrical mast concept was found structurally inferior to the rectangular section and was not pursued further.

## 10. Comparison and Weight Reduction Summary

### 10.1 E-ARM#1 (Side Arm) – Ø508 mm Electrode

Parameter | Mast 1 (600 × 410 mm) | Mast 2 (550 × 350 mm)
Von Mises Stress – Max (in mast) | 131.5 MPa | 102.88 MPa (−21.76%)
Total Deformation – Max | 34.247 mm | 41.56 mm (+21.4%)
Hydraulic Cylinder Base Load | 192.48 kN | 178.84 kN (−7.1%)
Verdict | Baseline | Improved – stress and base load both reduced

For the side arm (E-ARM#1, Ø508 mm electrode), the redesigned Mast 2 reduces both peak stress (~21.76%) and base load (~7.1%), confirming a genuine structural improvement despite the moderate increase in tip deformation.

### 10.2 Weight and Cost Reduction Summary

The mast weights for each configuration, obtained from SolidWorks mass properties, are summarized below along with the resulting weight and cost savings. The material cost is estimated at ₹400/kg — this reflects the cost of processed and fabricated structural steel (S355), accounting for cutting, welding, forming, and surface treatment, and is not simply the raw material price.

Configuration | Mast 1 Weight (kg) | Mast 2 Weight (kg) | Weight Reduction | Cost Saving
E-ARM#1, Ø508 mm | 5309 | 4518.9 | 790.1 kg (14.9%) | ≈ ₹3.16 lakhs
E-ARM#2, Ø508 mm | 6234 | 5274.8 | 959.2 kg (15.4%) | ≈ ₹3.84 lakhs
E-ARM#1, Ø457 mm | 4663.3 | 3609.8 (proposed) | 1053.5 kg (22.6%) | ≈ ₹4.21 lakhs
E-ARM#2, Ø457 mm | 6221.4 | 4951.17 | 1270.2 kg (20.4%) | ≈ ₹5.08 lakhs

Across all four configurations, the weight reduction ranges from approximately 15% to 23%, with the corresponding cost saving ranging from roughly ₹3.2 lakhs to ₹5.1 lakhs per mast (at ₹400/kg for processed fabricated steel). These figures represent the core quantified outcome of the project. Note that for E-ARM#1 (Ø457 mm), the Mast 2 figures are based on the proposed redesign described in Section 9.3.2, applied by analogy with the validated E-ARM#2 (Ø457 mm) results, rather than a dedicated ANSYS re-analysis.

### 10.3 E-ARM#2 (Middle Arm) – Ø508 mm Electrode

Parameter | Mast 1 (600 × 410 mm) | Mast 2 (550 × 350 mm)
Von Mises Stress – Max | 91.017 MPa | 91.02 MPa
Total Deformation – Max | 32.878 mm | 39.875 mm (+21%)

Mast Weight | 6234 kg | 5274.8 kg (−15.4%)
Verdict | Baseline | Peak stress essentially unchanged; mast weight reduced by ~15.4%

The redesigned middle-arm mast achieves an almost identical peak stress (~91 MPa for both) while reducing mast weight by ~15.4%, confirming that the added top plate effectively compensates for the reduced cross-section.

### 10.4 E-ARM#1 (Side Arm) – Ø457 mm Electrode

Parameter | Mast 1 (550 × 400 mm)
Von Mises Stress – Max | 123.29 MPa
Total Deformation – Max | 38.004 mm
Mast Weight | 4663.3 kg
Hydraulic Cylinder Base Load | 175,360 N

As noted in Section 9.3.2, a dedicated redesign-and-reanalysis cycle was not performed for this configuration. Instead, based on the favourable results already validated for the Ø508 mm side arm and the Ø457 mm middle arm, it was concluded that the same redesign (550 × 400 mm → 500 × 310 mm, with the 40 mm plate increased to 42 mm and the 25 mm plate reduced to 20 mm) could be applied directly to the Ø457 mm side arm to achieve comparable stress and weight reductions. The estimated Mast 2 weight, based on this proposed redesign, is 3609.8 kg — a reduction of ≈1053.5 kg (22.6%) and an estimated cost saving of ≈₹4.21 lakhs.

### 10.5 E-ARM#2 (Middle Arm) – Ø457 mm Electrode

Parameter | Mast 1 (550 × 400 mm) | Mast 2 (500 × 310 mm)
Von Mises Stress – Max | 92.214 MPa | 83.724 MPa (−9.2%)
Total Deformation – Max | 34.583 mm | 46.614 mm (+34.8%)
Mast Weight | 6221.4 kg | 4951.17 kg (−20.4%)
Hydraulic Cylinder Base Load | 183,380 N | 165,870 N (−9.5%)
Verdict | Baseline | Stress, load, and weight all reduced; deformation increase within allowable limits

The redesigned mast (500 × 310 mm with revised plate thicknesses: 42 mm major-axis, 20 mm minor-axis) achieves a meaningful reduction in peak stress (~9.2%), base load (~9.5%), and weight (~20.4%) — the largest weight saving among all configurations studied. The corresponding increase in total deformation (~35%) remains within the project's allowable deflection limit.

### 10.6 Overall Summary – All Four Configurations

Configuration | Mast 1 X-sec | Mast 2 X-sec | Stress Change | Weight Change | Base Load Change
E-ARM#1, Ø508 mm | 600×410 | 550×350 | −21.76% | −14.9% | −7.1%
E-ARM#2, Ø508 mm | 600×410 | 550×350 | ≈ 0% | −15.4% | ≈ 0% (roller reactions)
E-ARM#1, Ø457 mm | 550×400 | 500×310 (proposed) | Expected ≈ −9% | −22.6% | Expected ≈ −9.5%
E-ARM#2, Ø457 mm | 550×400 | 500×310 | −9.2% | −20.4% | −9.5%

Across all configurations studied, the reduced mast cross-section achieves equal or lower peak stress while reducing mast weight by approximately 15–23% and the load on the hydraulic cylinder base by roughly 7– 10%, confirming a genuine and consistent reduction in structural weight across the product range. Cost savings, estimated at ₹400/kg for processed fabricated steel, range from roughly ₹3.2 lakhs to ₹5.1 lakhs per mast. The trade-off in all redesigned cases is an increase in total deformation, which in every case remains within the allowable deflection limit for the assembly.

## 11. Conclusions

This 6-week internship project at SMS India Pvt. Ltd. demonstrated a structured FEA-based approach to evaluate and redesign the electrode mast of a Ladle Heating Furnace for weight and cost reduction. Key conclusions:

- The complete electrode mast-arm assembly (mast, arm, electrode, insulating plate, rollers, hydraulic cylinder) was successfully modelled in SolidWorks with simplification, density adjustment, and FOS-based conservative loading.
- Bolt pretension has a negligible effect on global deformation and stress fields, allowing computationally efficient bonded-contact models for this scale of analysis.
- 100 mm mesh element size is adequate for global structural response of these assemblies (mast height 6.8–9.5 m, total assembly height up to ~15 m), confirmed by a mesh sensitivity study (Δ < 0.2 mm at 75 mm mesh).
- The 8-roller guide system (4 pairs: front/back, left/right, upper/lower) is correctly modelled with the moment-resisting roller pair given fixed support and a frictional contact (μ = 0.03) against the mast, while the opposite thermal-gap roller pair remains disengaged to accommodate thermal expansion. Roller vertical spacing is 3100 mm for the Ø508 mm electrode and 2900 mm for the Ø457 mm electrode.
- For E-ARM#1 (Ø508 mm electrode, side arm): The redesigned mast (550 × 350 mm, with a stiffener plate added at the mast top) reduces peak stress by ~21.76% (131.5 → 102.88 MPa) and base load by ~7.1%, with a measured weight reduction of 14.9% (≈790 kg per mast) and an estimated cost saving of ≈₹3.16 lakhs per mast (at ₹400/kg for processed fabricated steel).
- For E-ARM#2 (Ø508 mm electrode, middle arm): The redesigned mast (550 × 350 mm, similar stiffener plate) maintains an almost identical peak stress (~91 MPa for both Mast 1 and Mast 2) while reducing mast weight by ~15.4% (≈959 kg per mast, ≈₹3.84 lakhs estimated saving), confirming the cross-section reduction did not compromise structural performance.
- For E-ARM#2 (Ø457 mm electrode, middle arm): The redesigned mast (500 × 310 mm, with major-axis plate increased to 42 mm and minor-axis plate reduced to 20 mm) reduces peak stress by ~9.2%, base load by ~9.5%, and weight by ~20.4% (≈1270 kg per mast, ≈₹5.08 lakhs estimated saving) — the largest weight saving among all configurations — while total deformation remains within the allowable limit.
- For E-ARM#1 (Ø457 mm electrode, side arm): Only the original 550 × 400 mm mast was directly analyzed (peak stress 123.29 MPa, weight 4663.3 kg). Based on the favourable results already obtained for the Ø508 mm side arm and the Ø457 mm middle arm, it was concluded that the same redesign (500 × 310 mm, 42 mm / 20 mm plates) could be applied directly to this configuration to achieve similar gains, with an estimated Mast 2 weight of 3609.8 kg (≈22.6% reduction, ≈₹4.21 lakhs estimated saving), without a further dedicated optimization cycle.
- A cylindrical mast alternative, analyzed under the same loading as the Ø508 mm middle arm Mast 1, showed both higher peak stress (95.471 MPa vs. 91.017 MPa) and higher total deformation (39.791 mm vs. 32.878 mm), confirming inferior bending stiffness compared to the rectangular section; this concept was not pursued further.
- All total and directional deformation values obtained across every configuration were within the allowable deflection limits for the assembly.

## 12. References and Acknowledgements

### 12.1 Software

- Dassault Systèmes SolidWorks – 3D CAD Modelling and Mass Properties
- ANSYS Mechanical 2019 Student – Static Structural Finite Element Analysis

### 12.2 Standards and Material

- EN 10025 / IS 2062: Structural Steel S355 / E350
- ANSYS Mechanical APDL – Static Structural Analysis Guide

### 12.3 Acknowledgements

The author sincerely thanks the entire Metallurgy Department team at SMS India Pvt. Ltd. for their guidance, mentorship, and provision of design data, CAD models, and reference calculations throughout this internship.

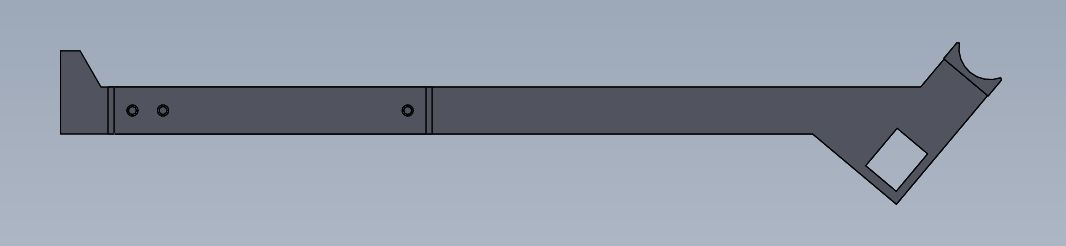
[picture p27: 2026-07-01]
508_Electrode/Side Mast 1/Photos 508 Side Mast 1/Screenshot 2026-06-23 161737.png

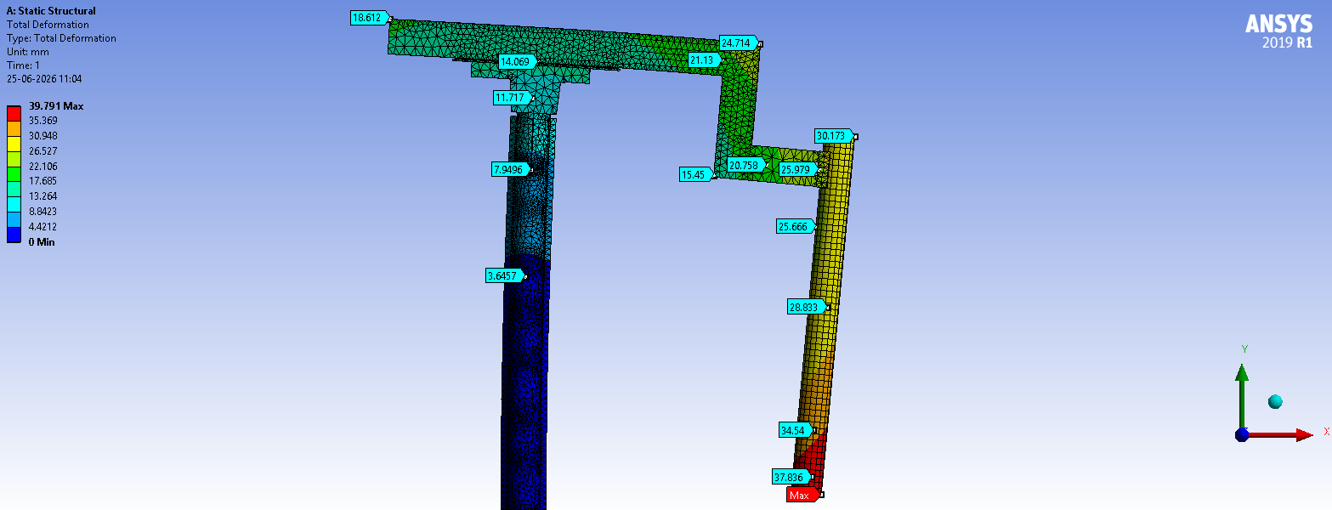
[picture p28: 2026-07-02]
Cylindrical_Mast/Cylindrical Middle Mast Photos/Screenshot 2026-06-25 110551.png

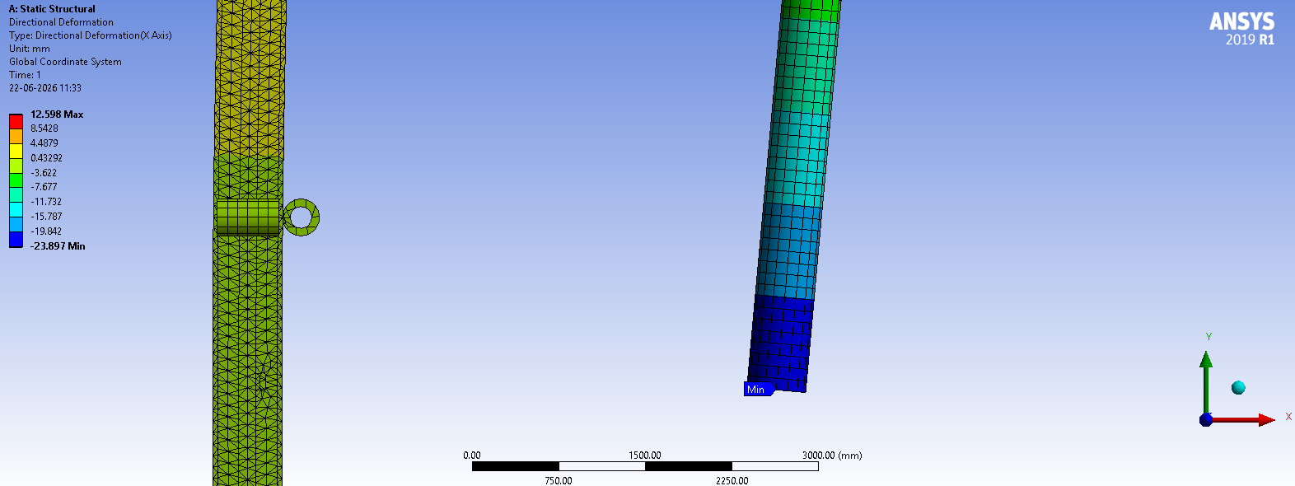
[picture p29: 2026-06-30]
508_Electrode/Middle Mast 1/Photos 508 Mast 1/Screenshot 2026-06-22 113419.png

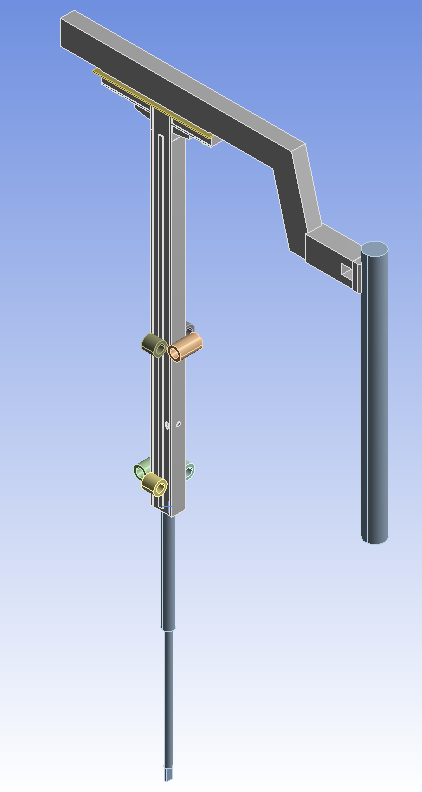
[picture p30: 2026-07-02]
457_Electrode/Middle Mast 2/Photos 457 Middle Mast 2/Screenshot 2026-06-26 133303.png

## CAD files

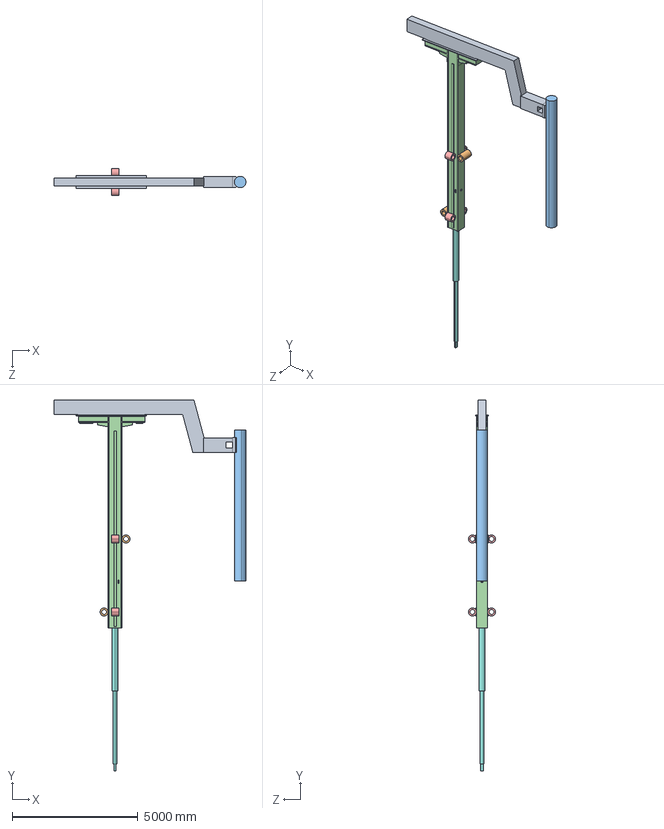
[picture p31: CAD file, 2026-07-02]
457_Electrode/Middle Mast 1/Case 2 Middle Arm Assembly.STEP
7623.3 x 14735.5 x 1080.0 mm
insulating plate
Roller x 2
Electrode 2 (2)
Case 2 Middle Mast 1
Roller 2 x 4
Bolt 1
Bolt 3
Hydraulic Cylinder
Case 2 Middle Arm

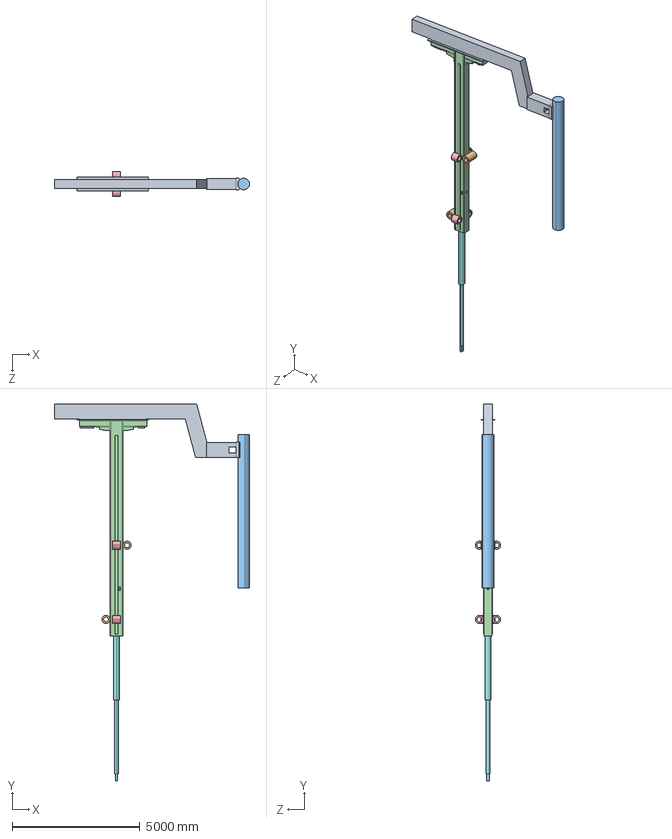
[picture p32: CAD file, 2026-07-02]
457_Electrode/Middle Mast 2/Case 2 Middle Arm Mast 2 Assembly.STEP
7623.3 x 14735.5 x 990.0 mm
insulating plate
Roller x 2
Electrode 2 (2)
Case 2 Middle Mast 2
Roller 2 x 4
Bolt 1
Bolt 3
Hydraulic Cylinder
Case 2 Middle Arm

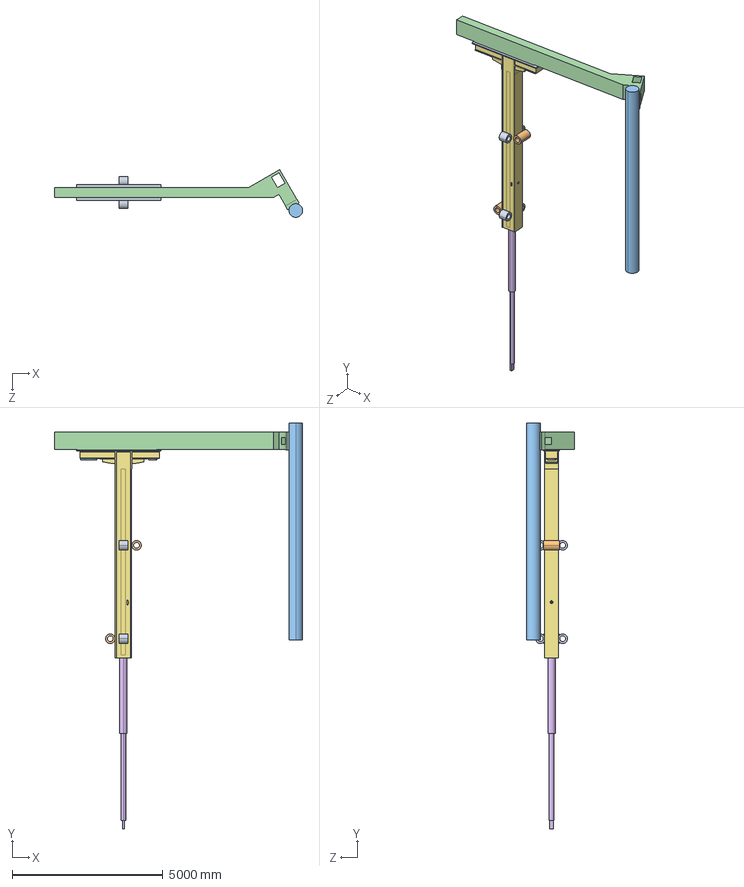
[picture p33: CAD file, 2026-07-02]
457_Electrode/Side Mast 1/Side Arm Assembly case 2.STEP
8240.9 x 13475.5 x 1586.1 mm
insulating plate 2
Roller x 2
Electrode 2
Side Arm 2
Bolt 3
Hydraulic Cylinder 2
Case 2 Mast 1
Bolt 1
Roller 2 x 4

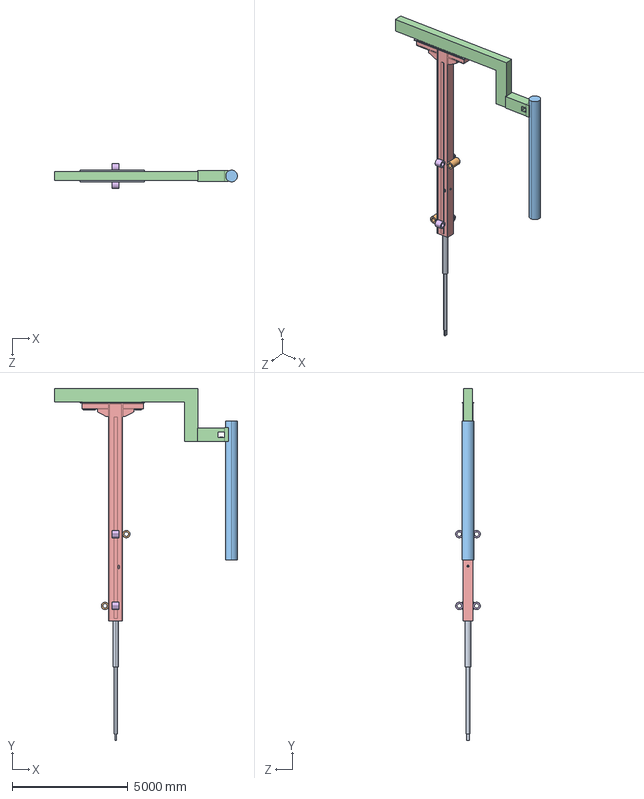
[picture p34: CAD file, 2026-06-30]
508_Electrode/Middle Mast 1/Middle Arm Assembly.STEP
7905.0 x 15203.5 x 1070.0 mm
insulating plate
Roller x 2
Electrode
electrode_arm_ansys_2
Electrode Mast
Roller 2 x 4
Bolt 1
Bolt 3
Hydraulic Cylinder

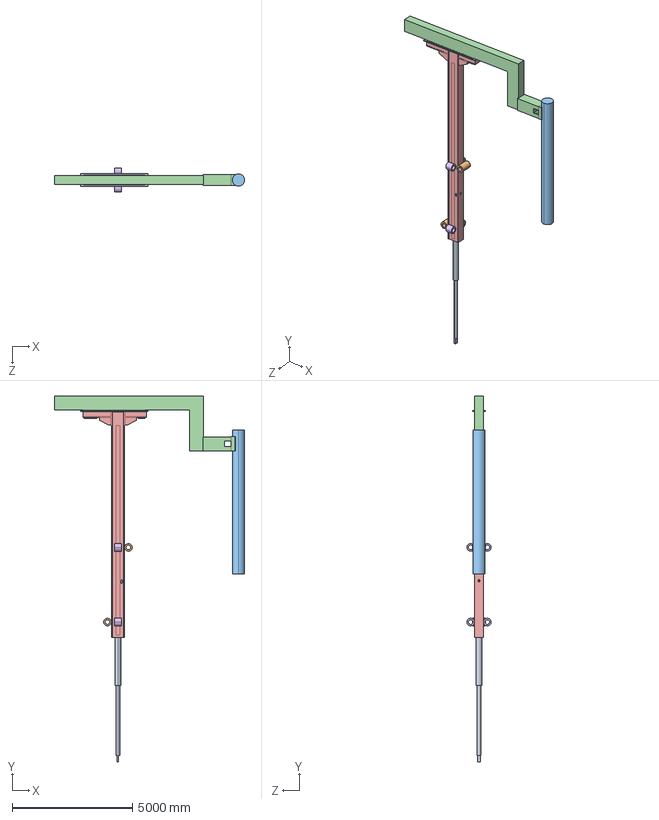
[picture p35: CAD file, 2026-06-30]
508_Electrode/Middle Mast 2/Middle Arm Assembly 2.STEP
7905.0 x 15203.5 x 1010.0 mm
insulating plate
Roller x 2
Electrode
electrode_arm_ansys_2
Electrode Mast 2
Roller 2 x 4
Bolt 1
Bolt 3
Hydraulic Cylinder

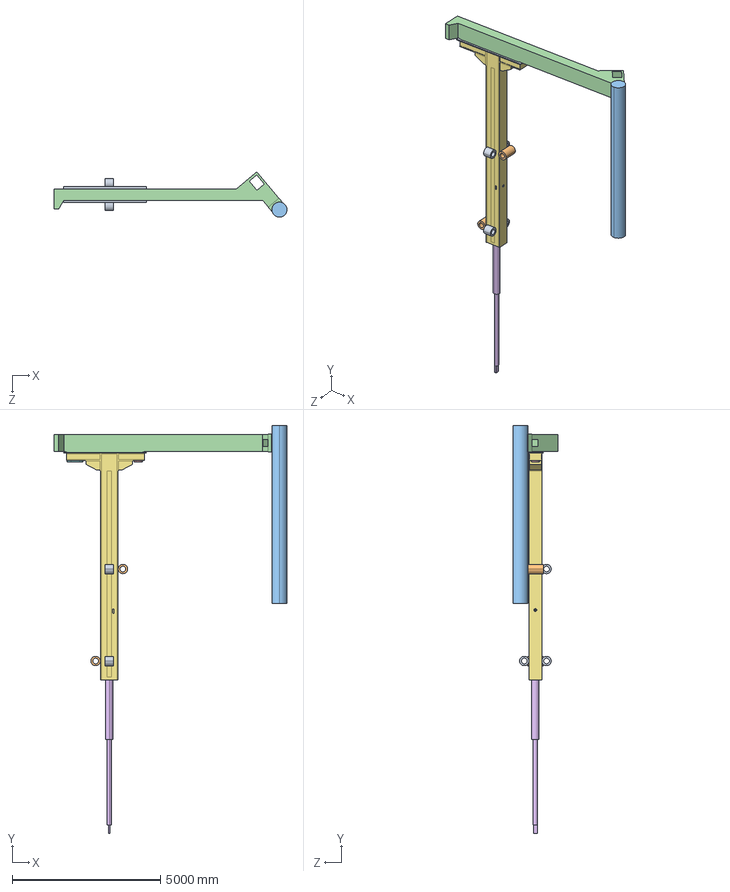
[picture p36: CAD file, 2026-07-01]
508_Electrode/Side Mast 1/Side Arm Assembly Final 1.STEP
7852.5 x 13750.5 x 1526.9 mm
insulating plate
Roller x 2
Electrode
Electrode Arm
Bolt 3
Hydraulic Cylinder
Electrode Mast 5
Bolt 1
Roller 2 x 4

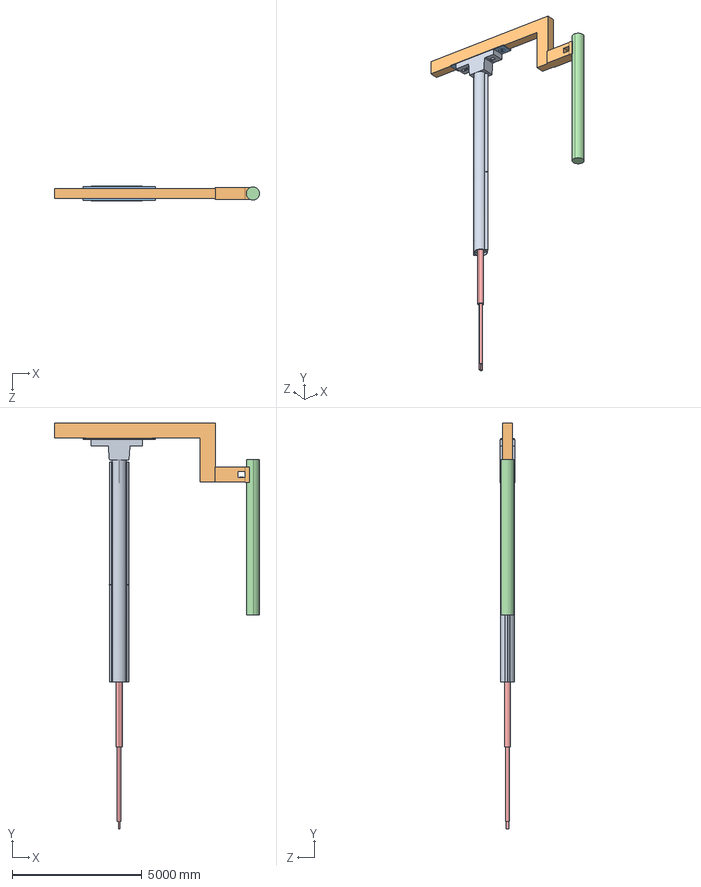
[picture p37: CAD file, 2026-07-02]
Cylindrical_Mast/Cylindrical Assembly Middle Arm.STEP
7905.0 x 15655.5 x 560.0 mm
Case 4 Mast
electrode_arm_ansys_2
insulating plate
Electrode
Hydraulic Cylinder
Support roller x 8

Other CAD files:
508_Electrode/Side Mast 2/Side Arm Assembly 2.STEP
